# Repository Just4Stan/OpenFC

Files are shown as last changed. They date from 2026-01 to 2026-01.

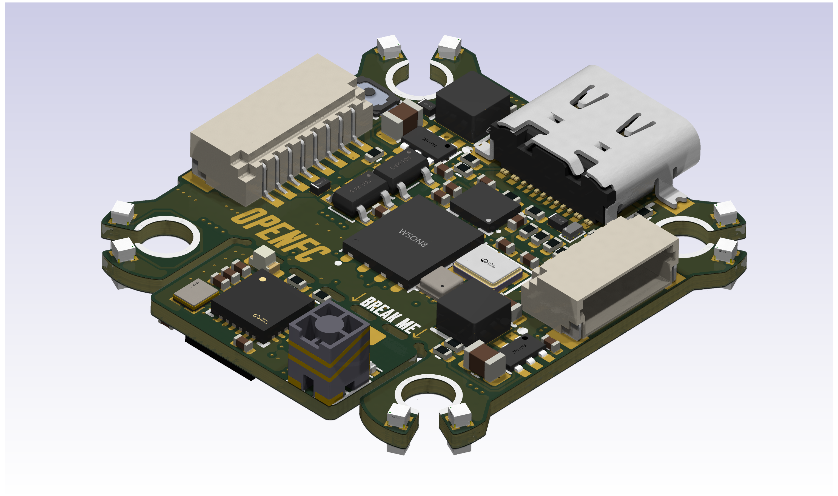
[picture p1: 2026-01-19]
images/OpenFC_Back.png

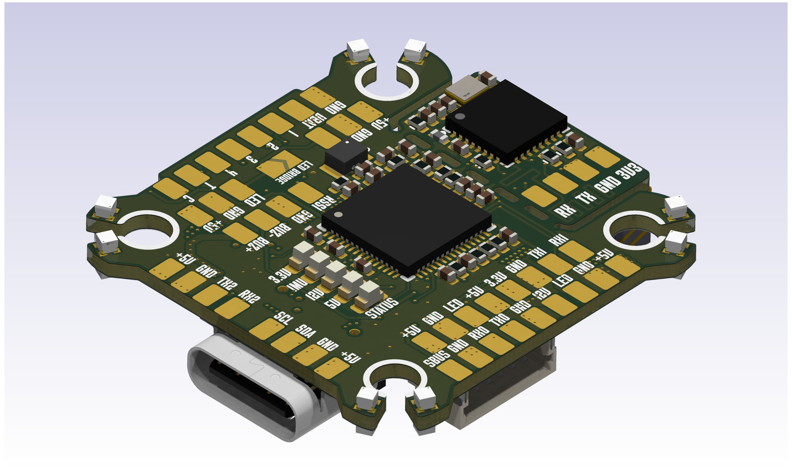
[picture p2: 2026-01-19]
images/OpenFC.png

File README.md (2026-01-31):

# OpenFC

Open-source Betaflight flight controller with integrated break-off ELRS receiver, based on the RP2354A microcontroller.


## Features

### Microcontroller
- **RP2354B** - Raspberry Pi dual-core ARM Cortex-M33 @ 150MHz (with integrated flash)

### Integrated ELRS Receiver (Break-off)
- On-board 2.4GHz ExpressLRS receiver module
- Break-off design allows for different placement if needed

### Sensors
- **IMU**: LSM6DSV16XTR 
- **Barometer**: BMI388

### Blackbox Data Logging
- **W25Q128JVPIQTR** - 128Mbit (16MB)

### Motor Outputs
- 4x PWM/DShot motor outputs

### Analog OSD on PIO
Hardware implementation of opamp and mux to detect syncs and select between white and black pixels. Needs software implementation still.

### Connectivity
- **USB-C** - Configuration and firmware flashing
- **UART0** - Serial RX/TX (ELRS connection pads)
- **UART1** - Spare serial port
- **PIO UART** - Software UART via RP2350 PIO (2x)
- **I2C** - External sensor expansion
- **SPI** - IMU and Blackbox on isolated bus.

### Analog Inputs
- Current sensor input (ADC)
- RSSI input (ADC)
- 1 external available ADC input

### Additional Features
- Addressable LED strip output (WS2812/NeoPixel)
- Buzzer output
- 16 LED's built in on corners
- ELRS ESP flashable by the RP2354B (BOOT/EN pins connected)

### Power
- 2S-6S batteries
- 10V and 5V regulated outputs, 10V is switchable.

## Repository Structure

```
OpenFC/
├── README.md
├── .gitignore
├── hardware/          ← KiCad project, libraries, and production files
│   ├── OpenFC.kicad_pro
│   ├── *.kicad_sch    ← Hierarchical schematics
│   ├── OpenFC.kicad_pcb
│   ├── lib.kicad_sym  ← Custom symbol library
│   ├── lib.pretty/    ← Custom footprint library
│   ├── lib.3dshapes/  ← 3D models
│   ├── production/    ← Gerbers, BOM, positions (all versions)
│   └── tools/         ← Analysis scripts
└── images/            ← Board renders
```

## Schematic Hierarchy

- `OpenFC.kicad_sch` - Top-level schematic
- `rp2350a.kicad_sch` - RP2354B microcontroller and supporting circuitry
- `elrs.kicad_sch` - ELRS 2.4GHz receiver module (break-off section)
- `Radioschematic.kicad_sch` - Radio/RF detailed schematic
- `power.kicad_sch` - Power supply and regulation
- `imu.kicad_sch` - LSM6DSV16XTR IMU
- `baro.kicad_sch` - BMP388 barometer
- `compass.kicad_sch` - LIS3MDLTR magnetometer (not populated, but there's space for it)
- `blackbox.kicad_sch` - W25Q128 flash memory
- `leds.kicad_sch` - Status LEDs
- `osd.kicad_sch` - OSD circuitry
- `connectors.kicad_sch` - External connectors
- `pads.kicad_sch` - Solder pads and test points

## Design Files

This project uses **KiCad 9.0** for schematic and PCB design. All symbol, footprint, and 3D model libraries are included in the repository — no external library setup is required.

## License

This project is open-source hardware. See LICENSE file for details.

## Contributing

Contributions are welcome! Please open an issue or submit a pull request.

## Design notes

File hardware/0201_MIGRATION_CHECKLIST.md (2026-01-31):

# 0201 Migration Checklist

## Summary
- Total passives: 33
- Can migrate to 0201: 31
- Cannot migrate: 2
- Already 0201: 0

## Can Migrate to 0201

| Ref | Value | Current Package | Notes |
|-----|---|---|---|
| C1 | 1u | 0402 |  |
| C3 | 10n | 0402 |  |
| C4 | 470n, 10V | 0402 |  |
| C5 | 10n | 0402 |  |
| C6 | 100n | 0402 |  |
| C7 | 100n | 0402 |  |
| C8 | 100n | 0402 |  |
| C10 | 1u 25v | 0402 |  |
| C11 | 10n | 0402 |  |
| C12 | 470n, 10V | 0402 |  |
| C13 | 10n | 0402 |  |
| C14 | 100n | 0402 |  |
| C15 | 100n | 0402 |  |
| C16 | 100n | 0402 |  |
| C17 | 10p | 0402 |  |
| C18 | 100n | 0402 |  |
| C19 | 1.2p | 0402 |  |
| C20 | 10p | 0402 |  |
| C21 | 100n | 0402 |  |
| C22 | 1.2p | 0402 |  |
| C23 | 1n | 0402 |  |
| C24 | 1u | 0402 |  |
| C25 | 1u | 0402 |  |
| C26 | 1.2p | 0402 |  |
| C27 | 1.2p | 0402 |  |
| R1 | 10k | 0402 |  |
| R2 | 10k | 0402 |  |
| R3 | 100k | 0402 |  |
| R4 | 100k | 0402 |  |
| R7 | 100k | 0402 |  |
| R8 | 100k | 0402 |  |

## Cannot Migrate

| Ref | Value | Current Package | Reason |
|-----|---|---|---|
| C2 | 2.2u | 0402 | Capacitance too high for 0201 |
| C9 | 10u | 0402 | Capacitance too high for 0201 |

## Already 0201

| Ref | Value |
|-----|---|

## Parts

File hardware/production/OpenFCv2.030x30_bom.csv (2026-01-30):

Designator | Footprint | Quantity | Value | LCSC Part #
1.8_IMU1, 12V1, 3V3CPU1, 5V1, 5V_PWR1, 5V_USB1, BL_FILT1, BPWM1, CLRSEL1, LEDLOW1, MUX_OUT1, PXLSEL1, SBUS1, SW12V1, SW5V1, SWC1, SWD1, SYNC1, SYNC_FILT1, SYNPWM1, VID_AC1, WH_FILT1, WPWM1 | TestPoint_Pad_D1.5mm | 23 | TestPoint
C1, C9 | 0402 | 2 | 10nF | C15195
C10, C11, C111, C12, C13, C14, C18, C19, C3, C32, C33, C34, C39, C41, C45, C46, C47, C49, C5, C50, C51, C52, C53, C55, C57, C58, C60, C61, C64, C70, C72, C75, C76, C78, C79, C8, C80, C81, C82, C83, C84, C85, C86, C87 | 0402 | 44 | 100n | C1525
C15 | 0402 | 1 | 1n
C16, C17, C2 | 0402 | 3 | 22uF | C105226
C35, C37 | 0805 | 2 | 4.7uF 50v | C98192
C36 | 0402 | 1 | 100nF | C1525
C38, C40, C48 | 0603 | 3 | 22uF | C2762594
C4, C6 | 0402 | 2 | 12p | C441742
C67, C68, C71, C77 | 0402 | 4 | 4.7uF | C23733
C7 | 0402 | 1 | 470nF | C92361
C73, C74 | 0402 | 2 | 20p | C441742
D1, D4, D5, D6, D7 | 0603 | 5 | LED_1_Green | C2994781
D2, D21, D3 | SOD-882_L1.0-W0.6-RD | 3 | RB161QS-40_C28646385 | C28646385
D8 | SOT-23-6_L2.9-W1.6-P0.95-LS2.8-BL | 1 | USBLC6-2SC6 | C7519
FL1, FL2 | FILTER-SMD_4P-L1.0-W0.5-L | 2 | DEA102700LT-6307A2 | C574024
J1, J10, J11, J12, J13, J14, J15, J16, J17, J18, J19, J2, J20, J21, J22, J23, J24, J25, J26, J27, J28, J29, J3, J30, J31, J32, J33, J34, J35, J36, J38, J39, J4, J40, J41, J42, J43, J44, J45, J46, J47, J48, J49, J5, J50, J51, J52, J53, J54, J55, J56, J57, J58, J59, J6, J7, J8, J9 | small_pad | 58 | 5V
L1 | IND-SMD_L2.0-W1.6_AOTA-B201610S3R3-101-T | 1 | AOTA-B201610S3R3-101-T | C42411119
L3, L4 | IND-SMD_L3.0-W3.0_AFE303020S | 2 | XRTC303020D4R7MBCA | C39846837
L7 | L0402 | 1 | LQG15HS2N0S02D | C18216
OSC1 | OSC-SMD_4P-L2.0-W1.6-BL_TXC_7Z | 1 | OW7EL89CENUNFAYLC-52M | C22434896
P1 | CONN-TH_SM08B-SRSS-TB-LF-SN | 1 | SM08B-SRSS-TB(LF)(SN) | C160407
Q1, Q2, Q7 | DFN-3L_L1.0-W0.6-P0.65-BR | 3 | DMN1150UFB-7B | C459538
R1, R3, R40, R47, R54, R6 | 0402 | 6 | 10k | C2909316
R10, R21, R30 | 0402 | 3 | 10k
R11, R13 | 0402 | 2 | 1k | C106235
R12, R15, R55 | 0402 | 3 | 200R | C25087
R14, R16, R17, R46, R5, R7 | 0402 | 6 | 100k | C60491
R18 | 0402 | 1 | 75R
R19 | 0402 | 1 | 10k | C25087
R2, R24 | 0402 | 2 | 1k
R20 | 0402 | 1 | 10k | C106235
R22, R4, R48, R49, R56 | 0402 | 5 | 30R | C138007
R23, R26, R34 | 0402 | 3 | 1k | C2909316
R25 | 0402 | 1 | 100k
R27, R32 | 0402 | 2 | 33R
R28 | 0402 | 1 | 5.23k | C2684530
R29 | 0402 | 1 | 470 | C114877
R31 | 0402 | 1 | 13.7k | C2933072
R33 | 0402 | 1 | 100R
R42 | 0402 | 1 | 6.8k | C105872
R43 | 0402 | 1 | 6.8k | C2906876
R51, R52 | 0402 | 2 | 5.1k | C105872
R8 | 0402 | 1 | 39k | C137995
RF1 | IPEX-SMD_3P-L2.6-W2.6-LS3.0 | 1 | CONUFL001-SMD-T | C22418213
U1 | CONN-SMD_SM06B-SRSS-TB-LF-SN | 1 | SM06B-SRSS-TB(LF)(SN) | C160405
U11 | UQFN-10_L1.8-W1.4-P0.40-TL | 1 | PI3A223ZMEX | C2673436
U12 | UDFN-4_L1.0-W1.0-P0.65-TL | 1 | WL9005D4-33 | C5357206
U13 | WSON-6-1EP_2x2mm_P0.65mm_EP1x1.6mm | 1 | TPS746-3.3DRV | C2868202
U14 | LGA-14_L3.0-W2.5-P0.50-BR | 1 | LSM6DSV16XTR | C5267406
U15, U16, U17, U18, U19, U22, U23, U24, U25, U26, U27, U28, U29, U3, U4, U5, U8 | LED-SMD_4P-L1.0-W1.0-TL_XL-1010RGBC-WS2812B | 17 | XL-1010RGBC-WS2812B | C5349953
U2 | QFN-32_L5.0-W5.0-P0.50-TL-EP3.7 | 1 | ESP32-C3FH4 | C2858491
U20 | QFN-24_L4.0-W4.0-P0.50-TL-EP2.6 | 1 | SX1281IMLTRT | C2151551
U21 | WDFN-6_L2.0-W2.0-P0.65-BL-EP | 1 | NCV8187AMT180TAG | C893189
U30 | SENSORM-SMD_BMP388 | 1 | BMP388 | C779278
U33 | SOT-583-8_L2.1-W1.6-P0.50-LS1.6-BL | 1 | TPS2116DRLR | C3235557
U36 | QFN-80_L10.0-W10.0-P0.40-TL-EP3.4 | 1 | RP2354B_C39843328 | C39843328
U37 | WSON-8-1EP_2x2mm_P0.5mm_EP0.9x1.6mm | 1 | GS8052-FR | C605423
U41 | SW-SMD_4P-L3.0-W2.0-P0.85-LS3.5 | 1 | TS2306A 240GF MSM 9_C2976675 | C2976675
U42 | SC-70-6_L2.0-W1.3-P0.65-LS2.1-BL | 1 | TXU0101DCKR | C5217868
U6, U7 | SOT-23-6_L2.9-W1.6-P0.95-LS2.9-BL | 2 | LMR51420YDDCR | C5383002
U9 | WSON-8_L6.0-W5.0-P1.27-BL-EP | 1 | BY25Q128ASWIG(R) | C394872
USB1 | USB-TYPE-C-SMD_TYPE-C-16P-QTWT | 1 | TYPE-C 16P QTWT | C5187472
X1 | CRYSTAL-SMD_4P-L2.5-W2.0-BL-A | 1 | XTM25012000JT00351001 | C37635340
X2 | CRYSTAL-SMD_4P-L1.6-W1.2-BL | 1 | SX0B40.000F0810F30 | C7301926

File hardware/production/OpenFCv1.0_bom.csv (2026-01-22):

Designator | Footprint | Quantity | Value | LCSC Part #
C1, C9 | 0402 | 2 | 10nF | C15195
C10, C11, C111, C12, C13, C14, C15, C18, C19, C2, C20, C24, C25, C26, C27, C28, C29, C30, C31, C32, C33, C34, C4, C41, C42, C44, C45, C46, C47, C49, C5, C50, C51, C52, C53, C54, C55, C56, C57, C58, C60, C69, C71, C75, C76, C8 | 0402 | 46 | 100n | C1525
C16, C17, C43 | 0402 | 3 | 22uF | C105226
C21, C22, C23, C6 | 0402 | 4 | 4.7uF | C23733
C3, C59 | 0402 | 2 | 15p | C441742
C35, C37 | 0805 | 2 | 4.7uF 50v | C98192
C36, C39 | 0402 | 2 | 100nF
C38, C40, C48 | 0603 | 3 | 22uF | C2762594
C7 | 0402 | 1 | 470nF | C92361
D1, D4, D5, D8 | 0603 | 4 | LED_1_Green | C2994781
D2 | SOT-23-6_L2.9-W1.6-P0.95-LS2.8-BL | 1 | USBLC6-2SC6 | C7519
D21, D3 | SOD-882_L1.0-W0.6-RD | 2 | RB161QS-40_C28646385 | C28646385
D6 | 0603 | 1 | LED_1_Green
FL1, FL2 | FILTER-SMD_4P-L1.0-W0.5-L | 2 | 2450FM07D0034T | C2651081
J1, J10, J11, J12, J13, J14, J15, J16, J17, J18, J19, J2, J20, J21, J22, J23, J24, J25, J26, J27, J28, J29, J3, J30, J31, J32, J33, J34, J35, J36, J38, J39, J4, J40, J42, J43, J44, J45, J46, J47, J48, J49, J5, J50, J53, J56, J6, J7, J8, J9 | small_pad | 50 | 5V
L1 | L0402 | 1 | BLM15AG601SN1D | C76884
L2 | IND-SMD_L2.0-W1.6_AOTA-B201610S3R3-101-T | 1 | AOTA-B201610S3R3-101-T | C42411119
L3, L4 | IND-SMD_L3.0-W3.0_AFE303020S | 2 | XRTC303020D4R7MBCA | C39846837
L7 | L0402 | 1 | LQG15HS2N0S02D | C18216
OSC1 | OSC-SMD_4P-L2.0-W1.6-BL_TXC_7Z | 1 | OW7EL89CENUNFAYLC-52M | C22434896
P1 | CONN-TH_SM08B-SRSS-TB-LF-SN | 1 | SM08B-SRSS-TB(LF)(SN) | C160407
Q7 | DFN-3L_L1.0-W0.6-P0.65-BR | 1 | DMN1150UFB-7B | C459538
R1, R11, R25, R26, R3, R6, R9 | 0402 | 7 | 10k | C2909316
R10, R34, R36, R37 | 0402 | 4 | 6.8k
R13 | 0402 | 1 | 1k | C106235
R14, R16, R5, R50, R7 | 0402 | 5 | 100k | C60491
R15, R20 | 0402 | 2 | 200R | C25087
R17, R18 | 0402 | 2 | 22R
R19, R21, R4 | 0402 | 3 | 33R | C25105
R2 | 0402 | 1 | 75 | C11702
R22 | 0402 | 1 | 30R
R23, R24, R44, R45 | 0402 | 4 | 5.1k | C105872
R28 | 0402 | 1 | 5.23k | C2684530
R29 | 0402 | 1 | 470 | C114877
R31 | 0402 | 1 | 13.7k | C2933072
R8 | 0402 | 1 | 39k | C137995
RF1 | IPEX-SMD_3P-L2.6-W2.6-LS3.0 | 1 | CONUFL001-SMD-T | C22418213
TP1, TP2, TP3 | TestPoint_Pad_D1.0mm | 3 | TestPoint
U1 | CONN-SMD_SM06B-SRSS-TB-LF-SN | 1 | SM06B-SRSS-TB(LF)(SN) | C160405
U10 | WSON-8_L6.0-W5.0-P1.27-TL-EP | 1 | GD25Q256EWIGR | C6564321
U12 | UDFN-4_L1.0-W1.0-P0.65-TL | 1 | WL9005D4-33 | C5357206
U13, U21 | WSON-6-1EP_2x2mm_P0.65mm_EP1x1.6mm | 2 | TPS746-3.3DRV
U14 | LGA-14_L3.0-W2.5-P0.50-BR | 1 | LSM6DSV16XTR | C5267406
U15, U16, U17, U18, U19, U22, U23, U24, U25, U26, U27, U28, U29, U3, U4, U5, U8 | LED-SMD_4P-L1.0-W1.0-TL_XL-1010RGBC-WS2812B | 17 | XL-1010RGBC-WS2812B | C5349953
U2 | QFN-32_L5.0-W5.0-P0.50-TL-EP3.7 | 1 | ESP32-C3FH4 | C2858491
U20 | QFN-24_L4.0-W4.0-P0.50-TL-EP2.6 | 1 | SX1281IMLTRT | C2151551
U30 | SENSORM-SMD_BMP388 | 1 | BMP388 | C779278
U32 | QFN-60_L7.0-W7.0-P0.40-TL-EP3.4 | 1 | RP2354A | C41378174
U33 | SOT-583-8_L2.1-W1.6-P0.50-LS1.6-BL | 1 | TPS2116DRLR | C3235557
U34 | SW-SMD_4P-L3.0-W2.0-P0.85-LS3.5 | 1 | TS2306A 240GF MSM 9_C2976675 | C2976675
U35 | QFN-32-1EP_5x5mm_P0.5mm_EP3.1x3.1mm | 1 | STM32G431KBUx | C1341901
U6, U7 | SOT-23-6_L2.9-W1.6-P0.95-LS2.9-BL | 2 | LMR51420YDDCR | C5383002
U9 | SC-70-6_L2.0-W1.3-P0.65-LS2.1-BL | 1 | TXU0101DCKR | C5217868
USB2 | USB-TYPE-C-SMD_TYPE-C-16P-QTWT | 1 | TYPE-C 16P QTWT | C5187472
X3 | OSC-SMD_4P-L1.6-W1.2-BL-1 | 1 | OT4EL89CJI-111YLC-12M | C42930209

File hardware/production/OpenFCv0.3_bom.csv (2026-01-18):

Designator | Footprint | Quantity | Value | LCSC Part #
AE1 | ANT-SMD_47948-0001 | 1 | 47948-0001 | C152351
C1, C9 | 0402 | 2 | 10nF | C15195
C11, C110, C111, C12, C13, C15, C2, C20, C24, C25, C26, C27, C28, C29, C30, C31, C34, C41, C42, C5, C8 | 0402 | 21 | 100n | C1525
C14, C17 | 0402 | 2 | 1.2p | C327292
C18, C19, C32, C33 | 0402 | 4 | 15p | C441742
C21, C22, C23, C6 | 0402 | 4 | 4.7uF | C23733
C3, C4 | 0402 | 2 | 22uF | C105226
C35, C37 | 0805 | 2 | 4.7uF 50v | C98192
C36, C39 | 0402 | 2 | 100nF
C38, C40 | 0603 | 2 | 22uF | C2762594
C7 | 0402 | 1 | 470nF | C92361
D1, D3, D4, D5 | 0603 | 4 | LED_1_Green | C2994781
D20, D21, D23 | SOD-882_L1.0-W0.6-RD | 3 | RB161QS-40_C28646385 | C28646385
D6 | 0603 | 1 | LED_1_Green
D7 | 0603 | 1 | LED | C2286
FL1 | FILTER-SMD_4P-L1.0-W0.5-L | 1 | 2450FM07D0034T | C2651081
J1, J13, J14, J15, J16, J17, J18, J19, J2, J20, J21, J22, J23, J24, J25, J26, J27, J28, J29, J3, J30, J31, J32, J33, J34, J35, J36, J37, J38, J39, J4, J40, J41, J42, J43, J44, J45, J46, J47, J48, J5, J53, J56, J59, J6, J7, J8, J9 | small_pad | 48 | 5V
L1 | 0402 | 1 | 3n | C269824
L2 | IND-SMD_L2.0-W1.6_AOTA-B201610S3R3-101-T | 1 | AOTA-B201610S3R3-101-T | C42411119
L3, L4 | IND-SMD_L3.0-W3.0_AFE303020S | 2 | XRTC303020D4R7MBCA | C39846837
L8 | L0402 | 1 | BLM15PD121SN1D | C76891
P1 | CONN-TH_SM08B-SRSS-TB-LF-SN | 1 | SM08B-SRSS-TB(LF)(SN) | C160407
Q7 | DFN-3L_L1.0-W0.6-P0.65-BR | 1 | DMN1150UFB-7B | C459538
R11, R25, R26, R6, R8, R9 | 0402 | 6 | 10k | C2909316
R13, R21 | 0402 | 2 | 1k | C106235
R14, R16, R5, R50 | 0402 | 4 | 100k | C60491
R15, R20 | 0402 | 2 | 200R | C25087
R17, R18 | 0402 | 2 | 22R
R19, R3, R4 | 0402 | 3 | 33R | C25105
R22 | 0402 | 1 | 30R
R23, R24, R44, R45 | 0402 | 4 | 5.1k | C105872
R28 | 0402 | 1 | 5.23k | C2684530
R29 | 0402 | 1 | 470 | C114877
R31 | 0402 | 1 | 13.7k | C2933072
R33 | 0402 | 1 | 3.3k | C25890
R35 | 0402 | 1 | 10k | C25744
R7 | 0402 | 1 | 12k | C2909316
U1 | CONN-SMD_SM06B-SRSS-TB-LF-SN | 1 | SM06B-SRSS-TB(LF)(SN) | C160405
U10, U9 | SOT-23-5_L3.0-W1.7-P0.95-LS2.8-BR | 2 | TLV75533PDBVR | C404027
U14 | LGA-14_L3.0-W2.5-P0.50-BR | 1 | LSM6DSV16XTR | C5267406
U15, U16, U17, U18, U22, U23, U24, U25, U26, U27, U28, U29, U3, U4, U5, U8 | LED-SMD_4P-L1.0-W1.0-TL_XL-1010RGBC-WS2812B | 16 | XL-1010RGBC-WS2812B | C5349953
U19 | QFN-32_L5.0-W5.0-P0.50-TL-EP3.7 | 1 | ESP8285H16 | C967019
U2 | WSON-8_L6.0-W5.0-P1.27-BL-EP | 1 | W25Q128JVPIQTR | C190862
U20 | QFN-24_L4.0-W4.0-P0.50-TL-EP2.6 | 1 | SX1281IMLTRT | C2151551
U30 | SENSORM-SMD_BMP388 | 1 | BMP388 | C779278
U32 | QFN-60_L7.0-W7.0-P0.40-TL-EP3.4 | 1 | RP2354A | C41378174
U33 | CRYSTAL-SMD_4P-L3.2-W2.5-BL | 1 | ABM8-272-T3_C20625731 | C20625731
U34 | SW-SMD_4P-L3.0-W2.0-P0.85-LS3.5 | 1 | TS2306A 240GF MSM 9_C2976675 | C2976675
U6, U7 | SOT-23-6_L2.9-W1.6-P0.95-LS2.9-BL | 2 | LMR51420YDDCR | C5383002
USB2 | USB-TYPE-C-SMD_TYPE-C-16P-QTWT | 1 | TYPE-C 16P QTWT | C5187472
X1 | CRYSTAL-SMD_4P-L2.0-W1.6-BL | 1 | XTM20026000FT00351005 | C37635330
X2 | CRYSTAL-SMD_4P-L2.0-W1.6-BL | 1 | Q22FA12800519 | C841202

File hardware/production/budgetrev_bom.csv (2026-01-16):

Designator | Footprint | Quantity | Value | LCSC Part #
AE2 | ANT-SMD_47948-0001 | 1 | 47948-0001 | C152351
C1, C2, C83, C84, C85, C86 | 0402 | 6 | 1.2p | C327292
C100, C101, C102, C103, C104, C107, C109, C110, C111, C113, C41, C46, C47, C48, C79, C80, C81, C82, C97, C98, C99 | 0402 | 21 | 100n | C1525
C105, C106 | 0402 | 2 | 15p | C441742
C108, C36, C39, C76, C77, C87, C90, C93, C95 | 0402 | 9 | 100nF
C3, C4 | 0402 | 2 | 22uF | C105226
C35, C37 | 0805 | 2 | 4.7uF 50v | C98192
C38, C40 | 0603 | 2 | 22uF | C2762594
C42, C43, C44, C45 | 0402 | 4 | 4.7uF | C23733
C78 | 0402 | 1 | 1uF
C88, C91, C94, C96 | 0402 | 4 | 10nF
C89, C92 | 0402 | 2 | 470nF
D1, D18, D2, D3, D4 | 0603 | 5 | LED_1_Green
D20, D21, D23 | SOD-882_L1.0-W0.6-RD | 3 | RB161QS-40_C28646385 | C28646385
FL3, FL4 | FILTER-SMD_5P-L2.0-W1.3-L | 2 | DEA202450BT-3030A1 | C307660
J1_2, J1, J10, J11, J12, J13, J14, J15, J16, J17, J18, J19, J2_2, J2, J20, J21, J22, J23, J24_2, J24, J25_2, J25, J26_2, J26, J27_2, J27, J28, J29, J3_2, J3, J30, J35, J36, J37, J38, J39, J4_2, J4, J40, J41, J42, J43, J44, J45, J46, J47, J48, J49, J5, J50, J51, J52, J53, J54, J55, J56, J57, J58, J6, J7, J8, J9 | small_pad | 62 | 5V
JP4 | RF-SMD_FRF05002-JSS103M | 1 | U.FL-R-SMT-1(80) | C88374
L1, L12 | L0805 | 2 | MGFL2012F150MT-LF (15uH) | C486333
L10, L11, L6 | L0402 | 3 | LQW15AN3N0B00D (3nH) | C269824
L2 | ANT-SMD_L8.0-W1.0-SLDA81-3R010G-S1TF | 1 | ANT8010LL04R2400A | C723634
L3, L4 | IND-SMD_L3.0-W3.0_AFE303020S | 2 | XRTC303020D4R7MBCA | C39846837
L5 | IND-SMD_PSTMAA160808-4R7MB | 1 | FTC160808S3R3MBCA | C46594346
LED2 | LED-SMD_4P-L2.0-W2.0-TL_WS2812B-2020 | 1 | WS2812B-2020 | C965555
OSC2 | OSC-SMD_4P-L2.0-W1.6-BL_TXC_7Z | 1 | OW7EL89CENUNFAYLC-52M | C22434896
P1 | CONN-TH_SM08B-SRSS-TB-LF-SN | 1 | SM08B-SRSS-TB(LF)(SN) | C160407
Q7 | DFN-3L_L1.0-W0.6-P0.65-BR | 1 | DMN1150UFB-7B | C459538
R1, R2, R44, R45 | 0402 | 4 | 5.1k
R19, R24, R40, R51 | 0402 | 4 | 10k
R20, R21, R22, R23 | 0402 | 4 | 100k | C25744
R27, R30, R5, R50 | 0402 | 4 | 100k
R28 | 0402 | 1 | 5.23k
R29 | 0402 | 1 | 470
R3, R4, R53 | 0402 | 3 | 30R
R31 | 0402 | 1 | 13.7k
R32 | 0402 | 1 | 200
R39 | 0402 | 1 | 33R
R41 | 0402 | 1 | 200R
R42, R43, R49 | 0402 | 3 | 1k
R46, R47 | 0402 | 2 | 22R
SW1 | KEY-SMD_B3U-1000PM | 1 | B3U-1000P | C231329
U1 | CONN-SMD_SM06B-SRSS-TB-LF-SN | 1 | SM06B-SRSS-TB(LF)(SN) | C160405
U10, U9 | SOT-23-5_L3.0-W1.7-P0.95-LS2.8-BR | 2 | TLV75533PDBVR | C404027
U11 | QFN-60_L7.0-W7.0-P0.40-TL-EP3.4 | 1 | RP2350A_C42411118 | C42411118
U12 | CRYSTAL-SMD_4P-L3.2-W2.5-BL | 1 | ABM8-272-T3_C20625731 | C20625731
U13 | USON-8_L3.0-W2.0-P0.50-BL-EP | 1 | W25Q32RVXHJQ TR | C32246052
U14 | LGA-14_L3.0-W2.5-P0.50-BR | 1 | LSM6DSV16XTR | C5267406
U15, U16, U17, U18, U3, U4, U5, U8 | LED-SMD_4P-L1.0-W1.0-TL_XL-1010RGBC-WS2812B | 8 | XL-1010RGBC-WS2812B | C5349953
U2 | WSON-8_L6.0-W5.0-P1.27-BL-EP | 1 | W25Q128JVPIQTR | C190862
U24, U25 | QFN-16_L3.0-W3.0-P0.50-BL-EP1.7 | 2 | RFX2401C | C19213
U26 | LGA-48_L7.0-W7.0-P0.50-BL-EP5.0 | 1 | ESP32-PICO-V3 | C967022
U27, U28 | QFN-24_L4.0-W4.0-P0.50-TL-EP2.6 | 2 | SX1281IMLTRT | C2151551
U30 | SENSORM-SMD_BMP388 | 1 | BMP388 | C779278
U31 | LGA-12_L2.0-W2.0-P0.50-BL | 1 | LIS3MDLTR | C478483
U6, U7 | SOT-23-6_L2.9-W1.6-P0.95-LS2.9-BL | 2 | LMR51420YDDCR | C5383002
USB1 | USB-C-SMD_TYPE-C-6PIN-2MD-073 | 1 | TYPE-C 16PIN 2MD(073) | C2765186

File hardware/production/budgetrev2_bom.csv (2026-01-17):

Designator | Footprint | Quantity | Value | LCSC Part #
AE1 | ANT-SMD_47948-0001 | 1 | 47948-0001 | C152351
C1, C9 | 0402 | 2 | 10nF | C15195
C10, C100, C101, C102, C103, C104, C109, C11, C110, C111, C12, C13, C2, C41, C46, C47, C48, C5, C8, C97, C98, C99 | 0402 | 22 | 100n | C1525
C105, C106, C18, C19 | 0402 | 4 | 15p | C441742
C14, C15, C17, C20 | 0402 | 4 | 1.2p | C327292
C3, C4 | 0402 | 2 | 22uF | C105226
C35, C37 | 0805 | 2 | 4.7uF 50v | C98192
C36, C39 | 0402 | 2 | 100nF
C38, C40 | 0603 | 2 | 22uF | C2762594
C42, C43, C44, C45 | 0402 | 4 | 4.7uF | C23733
C7 | 0402 | 1 | 470nF | C92361
D1, D3, D4, D5 | 0603 | 4 | LED_1_Green | C2994781
D2 | 0603 | 1 | LED_1_Green
D20, D21, D23 | SOD-882_L1.0-W0.6-RD | 3 | RB161QS-40_C28646385 | C28646385
J1, J13, J14, J15, J16, J17, J18, J19, J2, J20, J21, J22, J23, J24, J25, J26, J27, J28, J29, J3, J30, J31, J32, J33, J34, J35, J36, J37, J38, J39, J4, J40, J41, J42, J43, J44, J45, J46, J47, J48, J5, J53, J56, J57, J59, J6, J7, J8 | small_pad | 48 | 5V
L13 | ANT-SMD_L8.0-W1.0-SLDA81-3R010G-S1TF | 1 | ANT8010LL04R2400A | C723634
L3, L4 | IND-SMD_L3.0-W3.0_AFE303020S | 2 | XRTC303020D4R7MBCA | C39846837
L5 | IND-SMD_PSTMAA160808-4R7MB | 1 | FTC160808S3R3MBCA | C46594346
L7, L9 | L0402 | 2 | LQW15AN3N0B00D (3nH) | C269824
L8 | L0402 | 1 | BLM15PD121SN1D | C76891
OSC1 | OSC-SMD_4P-L2.0-W1.6-BL_TXC_7Z | 1 | OW7EL89CENUNFAYLC-52M | C22434896
P1 | CONN-TH_SM08B-SRSS-TB-LF-SN | 1 | SM08B-SRSS-TB(LF)(SN) | C160407
Q7 | DFN-3L_L1.0-W0.6-P0.65-BR | 1 | DMN1150UFB-7B | C459538
R1, R2, R44, R45 | 0402 | 4 | 5.1k | C105872
R10, R11, R12, R6, R8, R9 | 0402 | 6 | 10k | C2909316
R13, R42 | 0402 | 2 | 1k | C106235
R14, R16, R5, R50 | 0402 | 4 | 100k | C60491
R15, R41 | 0402 | 2 | 200R | C25087
R28 | 0402 | 1 | 5.23k | C2684530
R29 | 0402 | 1 | 470 | C114877
R3, R39, R4 | 0402 | 3 | 33R | C25105
R31 | 0402 | 1 | 13.7k | C114877
R46, R47 | 0402 | 2 | 22R
R53 | 0402 | 1 | 30R
R7 | 0402 | 1 | 12k | C2909316
U1 | CONN-SMD_SM06B-SRSS-TB-LF-SN | 1 | SM06B-SRSS-TB(LF)(SN) | C160405
U10, U9 | SOT-23-5_L3.0-W1.7-P0.95-LS2.8-BR | 2 | TLV75533PDBVR | C404027
U11 | QFN-60_L7.0-W7.0-P0.40-TL-EP3.4 | 1 | RP2350A_C42411118 | C42411118
U12 | CRYSTAL-SMD_4P-L3.2-W2.5-BL | 1 | ABM8-272-T3_C20625731 | C20625731
U13 | USON-8_L3.0-W2.0-P0.50-BL-EP | 1 | W25Q32RVXHJQ TR | C32246052
U14 | LGA-14_L3.0-W2.5-P0.50-BR | 1 | LSM6DSV16XTR | C5267406
U15, U16, U17, U18, U3, U4, U5, U8 | LED-SMD_4P-L1.0-W1.0-TL_XL-1010RGBC-WS2812B | 8 | XL-1010RGBC-WS2812B | C5349953
U19 | QFN-32_L5.0-W5.0-P0.50-TL-EP3.7 | 1 | ESP8285H16 | C967019
U2 | WSON-8_L6.0-W5.0-P1.27-BL-EP | 1 | W25Q128JVPIQTR | C190862
U20 | QFN-24_L4.0-W4.0-P0.50-TL-EP2.6 | 1 | SX1281IMLTRT | C2151551
U21 | SW-SMD_4P-L3.0-W2.0-P0.85-LS3.5 | 1 | TS2306A 240GF MSM 9_C2976675 | C2976675
U30 | SENSORM-SMD_BMP388 | 1 | BMP388 | C779278
U6, U7 | SOT-23-6_L2.9-W1.6-P0.95-LS2.9-BL | 2 | LMR51420YDDCR | C5383002
USB2 | USB-TYPE-C-SMD_TYPE-C-16P-QTWT | 1 | TYPE-C 16P QTWT | C5187472
X1 | CRYSTAL-SMD_4P-L2.0-W1.6-BL | 1 | XTM20026000FT00351005 | C37635330

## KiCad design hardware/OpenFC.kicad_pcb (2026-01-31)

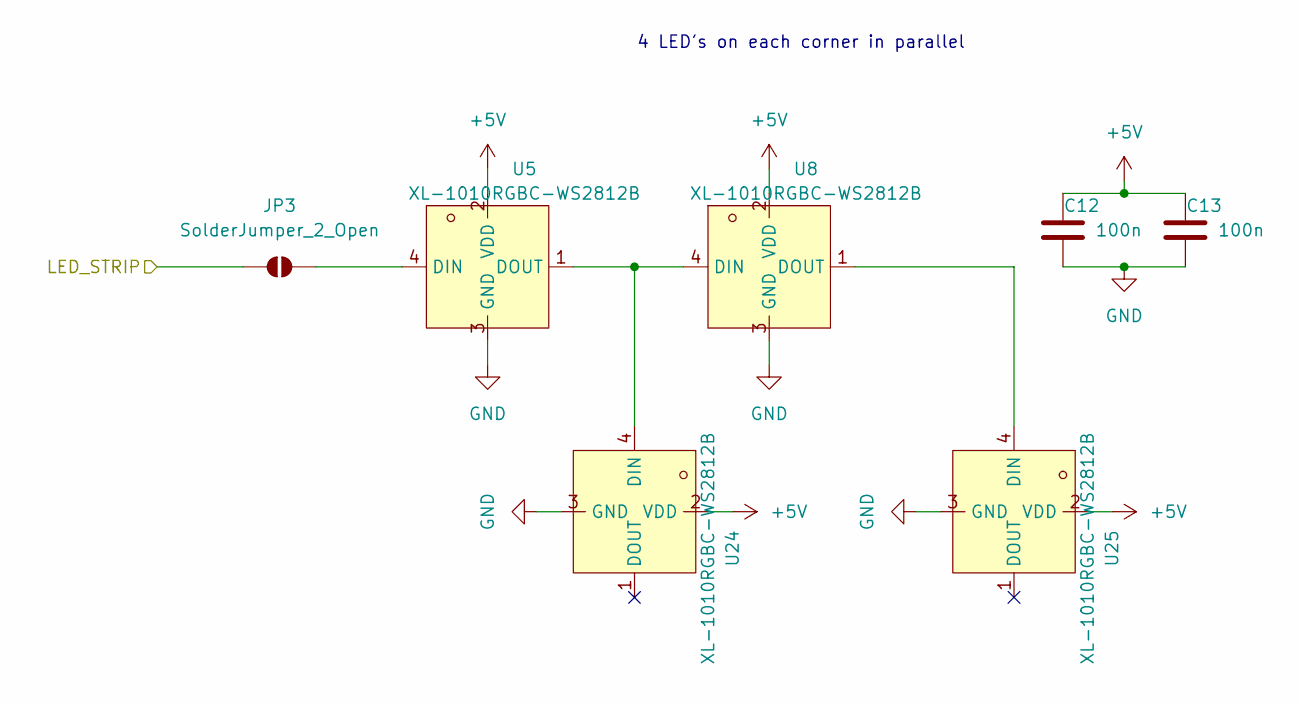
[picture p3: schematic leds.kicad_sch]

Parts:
C12, C13: 100n; C_0201_0603Metric; LCSC C76939
JP3: SolderJumper_2_Open; MouseBite-Slot-Jumper_0201
U5, U8, U24, U25: XL-1010RGBC-WS2812B; LED-SMD_4P-L1.0-W1.0-TL_XL-1010RGBC-WS2812B; LCSC Part C5349953

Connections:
+5V: C12.1, C13.1, U5.2 (VDD), U8.2 (VDD), U24.2 (VDD), U25.2 (VDD); also elsewhere on the board
/LED: JP3.1 (A); also elsewhere on the board
GND: C12.2, C13.2, U5.3 (GND), U8.3 (GND), U24.3 (GND), U25.3 (GND); also elsewhere on the board
unnamed: JP3.2 (B), U5.4 (DIN)
unnamed: U5.1 (DOUT), U8.4 (DIN), U24.4 (DIN)
unnamed: U8.1 (DOUT), U25.4 (DIN)

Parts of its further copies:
C18, C19, C46, C47, C57, C58: 100n; C_0201_0603Metric; LCSC C76939
JP1, JP2, JP4: SolderJumper_2_Open; MouseBite-Slot-Jumper_0201
U3, U4, U15, U16, U17, U18, U22, U23, U26, U27, U28, U29: XL-1010RGBC-WS2812B; LED-SMD_4P-L1.0-W1.0-TL_XL-1010RGBC-WS2812B; LCSC Part C5349953

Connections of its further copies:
+5V: C18.1, C19.1, C46.1, C47.1, C57.1, C58.1, U3.2 (VDD), U4.2 (VDD), U15.2 (VDD), U16.2 (VDD), U17.2 (VDD), U18.2 (VDD), U22.2 (VDD), U23.2 (VDD), U26.2 (VDD), U27.2 (VDD), U28.2 (VDD), U29.2 (VDD); also elsewhere on the board
/LED: JP1.1 (A), JP2.1 (A), JP4.1 (A); also elsewhere on the board
GND: C18.2, C19.2, C46.2, C47.2, C57.2, C58.2, U3.3 (GND), U4.3 (GND), U15.3 (GND), U16.3 (GND), U17.3 (GND), U18.3 (GND), U22.3 (GND), U23.3 (GND), U26.3 (GND), U27.3 (GND), U28.3 (GND), U29.3 (GND); also elsewhere on the board
unnamed: JP1.2 (B), U3.4 (DIN)
unnamed: JP2.2 (B), U17.4 (DIN)
unnamed: JP4.2 (B), U26.4 (DIN)
unnamed: U3.1 (DOUT), U4.4 (DIN), U15.4 (DIN)
unnamed: U15.1 (DOUT), U16.4 (DIN)
unnamed: U17.1 (DOUT), U18.4 (DIN), U22.4 (DIN)
unnamed: U22.1 (DOUT), U23.4 (DIN)
unnamed: U26.1 (DOUT), U27.4 (DIN), U28.4 (DIN)
unnamed: U28.1 (DOUT), U29.4 (DIN)

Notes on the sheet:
4 LED's on each corner in parallel

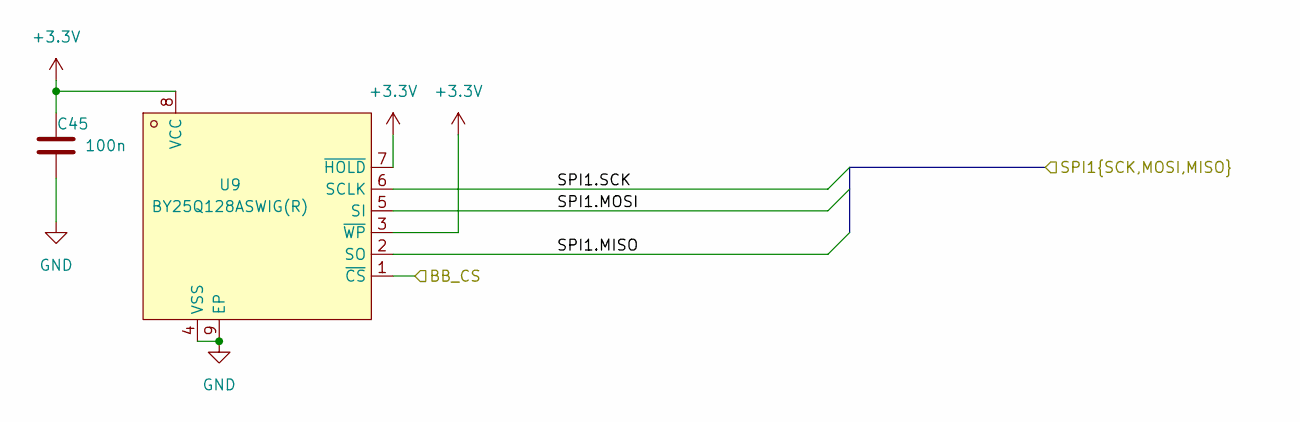
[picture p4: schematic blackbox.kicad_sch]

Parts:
C45: 100n; C_0201_0603Metric; LCSC C76939
U9: BY25Q128ASWIG(R); WSON-8_L6.0-W5.0-P1.27-BL-EP; LCSC Part C394872

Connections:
+3.3V: C45.1, U9.3 (~WP), U9.7 (~HOLD), U9.8 (VCC); also elsewhere on the board
/BLACKBOX/BB_CS: U9.1 (~CS); also elsewhere on the board
/BLACKBOX/SPI1.MISO: U9.2 (SO); also elsewhere on the board
/BLACKBOX/SPI1.MOSI: U9.5 (SI); also elsewhere on the board
/BLACKBOX/SPI1.SCK: U9.6 (SCLK); also elsewhere on the board
GND: C45.2, U9.4 (VSS), U9.9 (EP); also elsewhere on the board

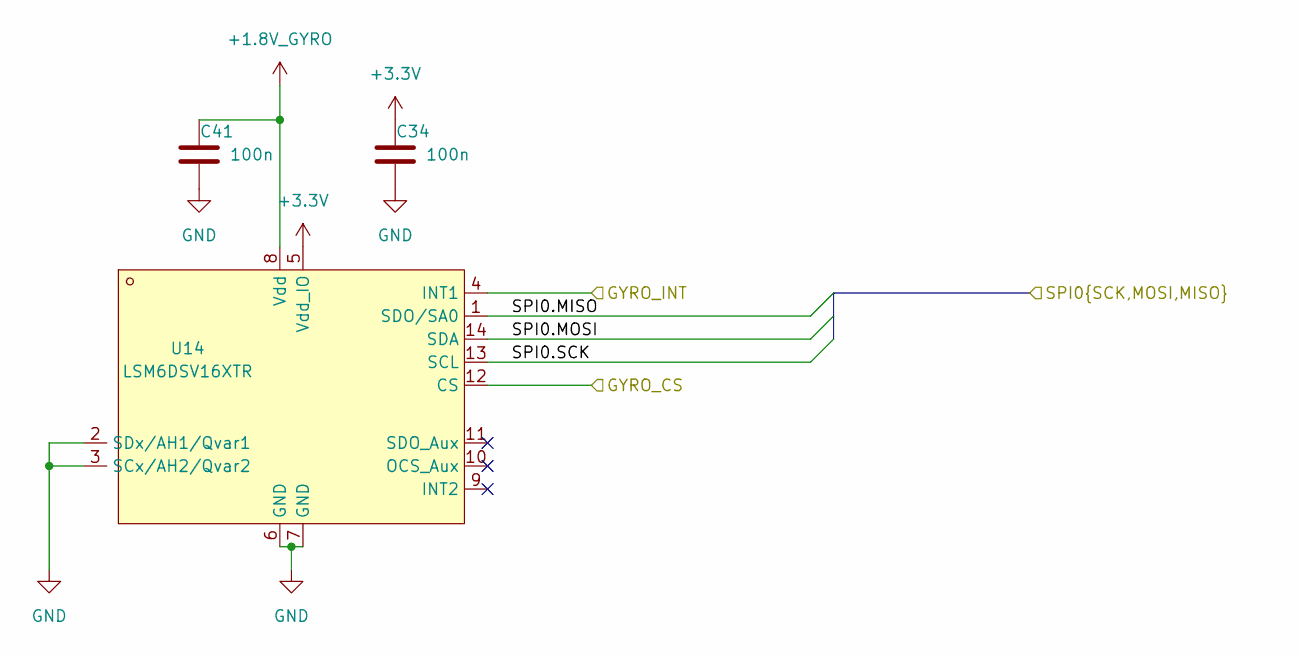
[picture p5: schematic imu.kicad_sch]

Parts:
C34, C41: 100n; C_0201_0603Metric; LCSC C76939
U14: LSM6DSV16XTR; LGA-14_L3.0-W2.5-P0.50-BR; LCSC Part C5267406

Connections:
+1.8V_GYRO: C41.1, U14.8 (Vdd); also elsewhere on the board
+3.3V: C34.1, U14.5 (Vdd_IO); also elsewhere on the board
/IMU/GYRO_CS: U14.12 (CS); also elsewhere on the board
/IMU/GYRO_INT: U14.4 (INT1); also elsewhere on the board
/IMU/SPI0.MISO: U14.1 (SDO/SA0); also elsewhere on the board
/IMU/SPI0.MOSI: U14.14 (SDA); also elsewhere on the board
/IMU/SPI0.SCK: U14.13 (SCL); also elsewhere on the board
GND: C34.2, C41.2, U14.2 (SDx/AH1/Qvar1), U14.3 (SCx/AH2/Qvar2), U14.6 (GND), U14.7 (GND); also elsewhere on the board

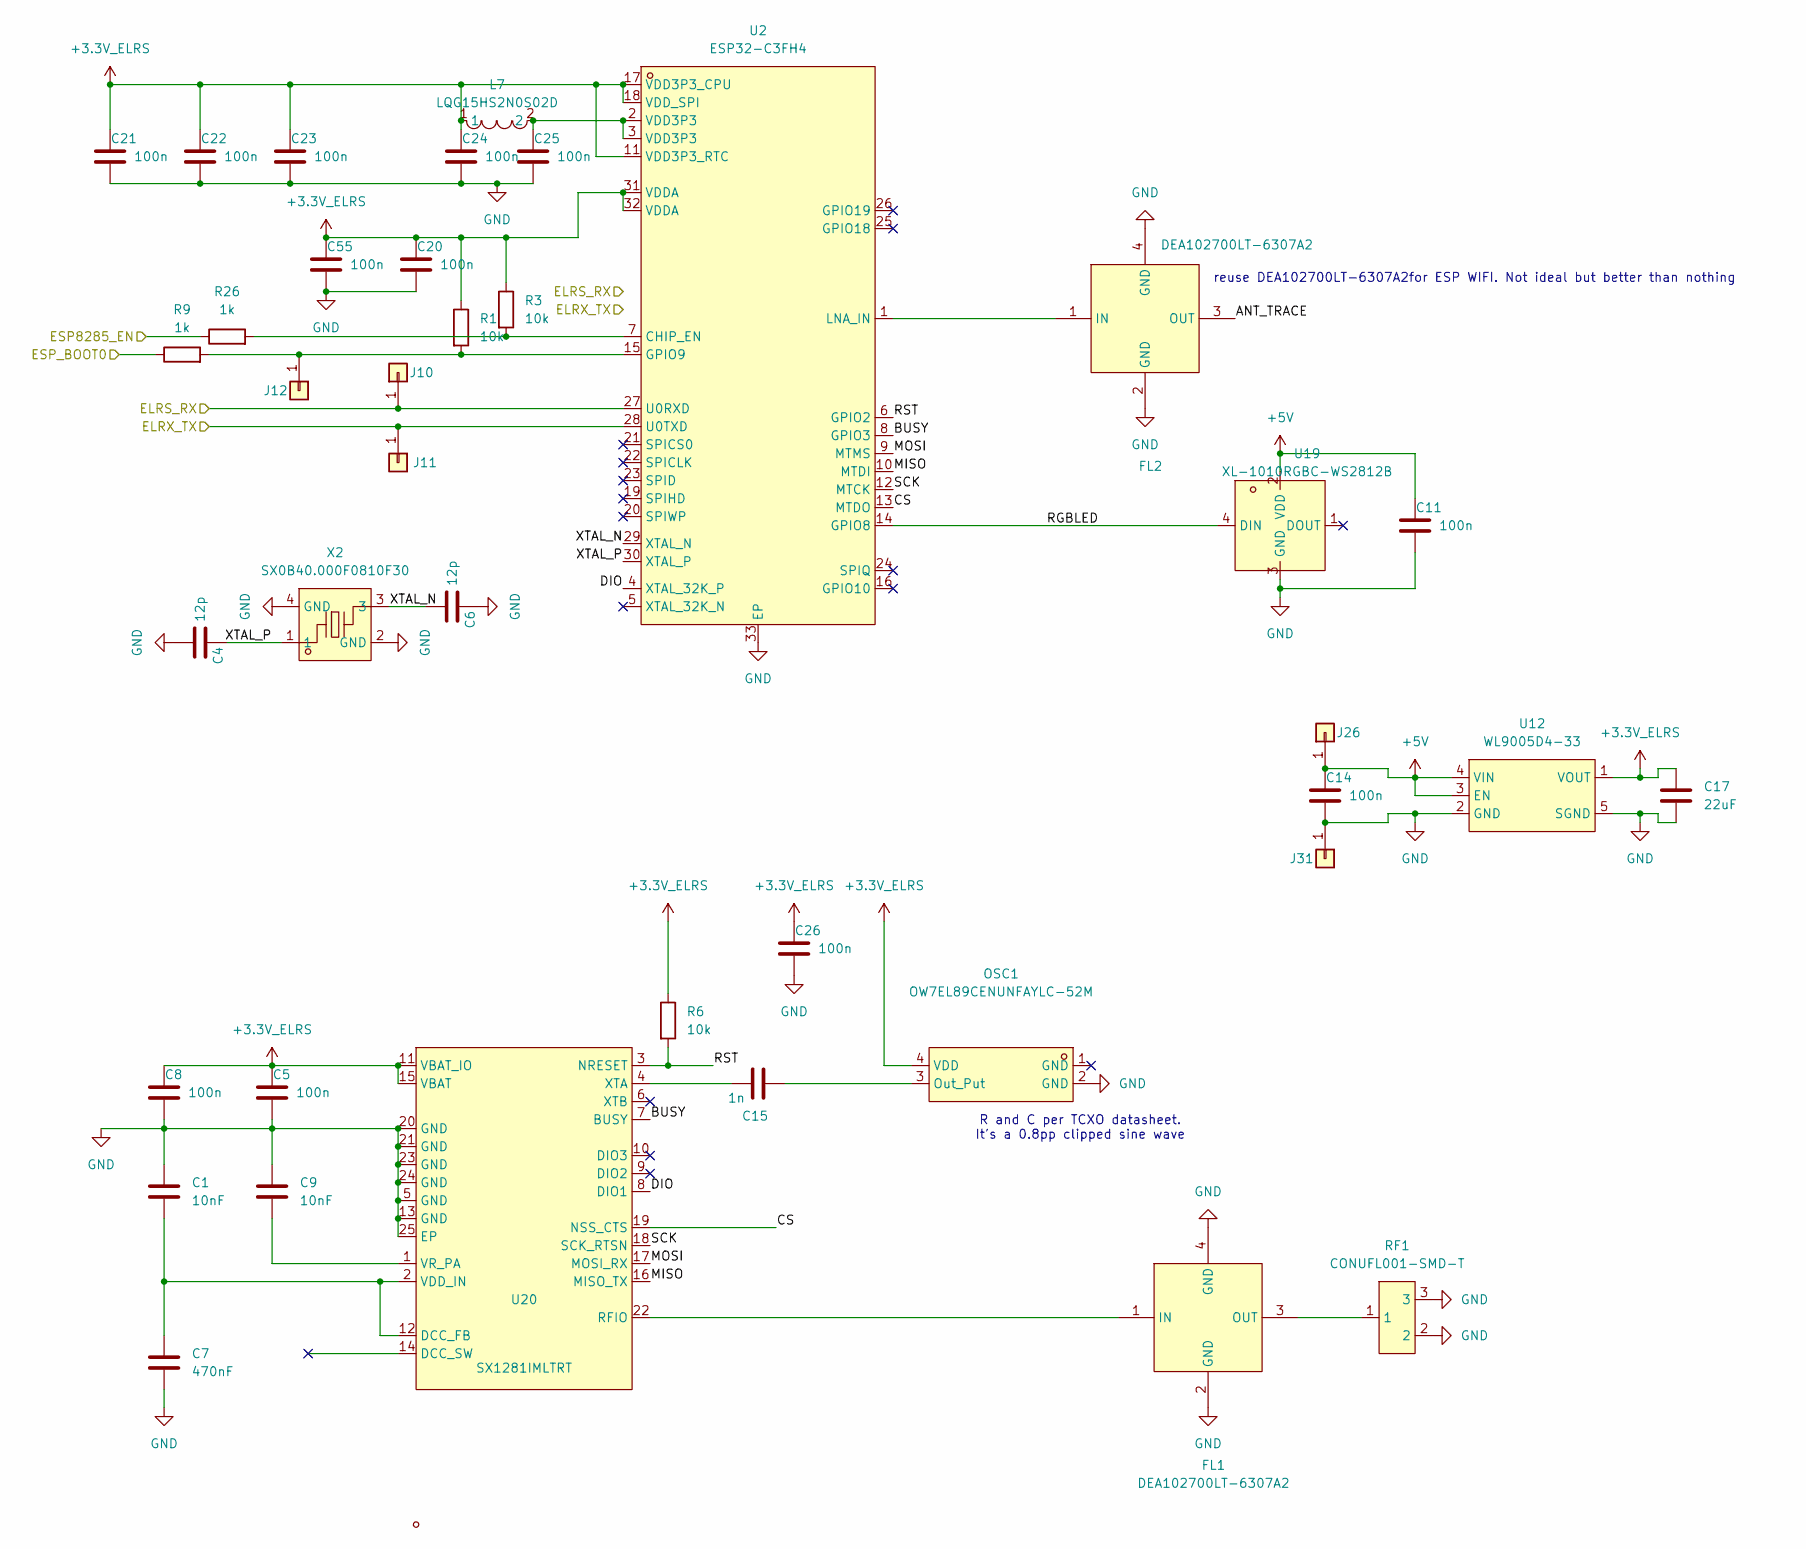
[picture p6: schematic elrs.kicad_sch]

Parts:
C1, C9: 10nF; C_0201_0603Metric; LCSC C76941
C4, C6: 12p; C_0201_0603Metric; LCSC C161404
C5, C8, C11, C14, C20, C21, C22, C23, C24, C25, C26, C55: 100n; C_0201_0603Metric; LCSC C76939
C7: 470nF; C_0201_0603Metric; LCSC C85926
C15: 1n; C_0201_0603Metric; LCSC C85934
C17: 22uF; C_0402_1005Metric; LCSC C105226
FL1, FL2: DEA102700LT-6307A2; FILTER-SMD_4P-L1.0-W0.5-L; LCSC Part C574024
J10, J11, J12, J26, J31: 5V; small_pad
L7: LQG15HS2N0S02D; L0402; LCSC Part C18216
OSC1: OW7EL89CENUNFAYLC-52M; OSC-SMD_4P-L2.0-W1.6-BL_TXC_7Z; LCSC Part C22434896
R1, R3, R6: 10k; C_0201_0603Metric; LCSC C473048
R9, R26: 1k; C_0201_0603Metric; LCSC C270365
RF1: CONUFL001-SMD-T; IPEX-SMD_3P-L2.6-W2.6-LS3.0; LCSC Part C22418213
U2: ESP32-C3FH4; QFN-32_L5.0-W5.0-P0.50-TL-EP3.7; LCSC Part C2858491
U12: WL9005D4-33; UDFN-4_L1.0-W1.0-P0.65-TL; LCSC Part C5357206
U19: XL-1010RGBC-WS2812B; LED-SMD_4P-L1.0-W1.0-TL_XL-1010RGBC-WS2812B; LCSC Part C5349953
U20: SX1281IMLTRT; QFN-24_L4.0-W4.0-P0.50-TL-EP2.6; LCSC Part C2151551
X2: SX0B40.000F0810F30; CRYSTAL-SMD_4P-L1.6-W1.2-BL; LCSC Part C7301926

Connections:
+3.3V_ELRS: C5.1, C8.1, C17.1, C20.1, C21.1, C22.1, C23.1, C24.1, C26.1, C55.1, L7.1, OSC1.4 (VDD), R1.1, R3.1, R6.1, U2.11 (VDD3P3_RTC), U2.17 (VDD3P3_CPU), U2.18 (VDD_SPI), U2.31 (VDDA), U2.32 (VDDA), U12.1 (VOUT), U20.11 (VBAT_IO), U20.15 (VBAT)
+5V: C11.1, C14.1, J26.1, U12.3 (EN), U12.4 (VIN), U19.2 (VDD); also elsewhere on the board
/ELRS/ANT_TRACE: FL2.3 (OUT)
/ELRS/BUSY: U2.8 (GPIO3), U20.7 (BUSY)
/ELRS/CS: U2.13 (MTDO), U20.19 (NSS_CTS)
/ELRS/DIO: U2.4 (XTAL_32K_P), U20.8 (DIO1)
/ELRS/ESP8285_EN: R26.1; also elsewhere on the board
/ELRS/ESP_BOOT0: R9.1; also elsewhere on the board
/ELRS/MISO: U2.10 (MTDI), U20.16 (MISO_TX)
/ELRS/MOSI: U2.9 (MTMS), U20.17 (MOSI_RX)
/ELRS/RGBLED: U2.14 (GPIO8), U19.4 (DIN)
/ELRS/RST: R6.2, U2.6 (GPIO2), U20.3 (NRESET)
/ELRS/SCK: U2.12 (MTCK), U20.18 (SCK_RTSN)
/ELRS/XTAL_N: C6.2, U2.29 (XTAL_N), X2.3
/ELRS/XTAL_P: C4.1, U2.30 (XTAL_P), X2.1
/UART1_RX: J11.1, U2.28 (U0TXD); also elsewhere on the board
/UART1_TX: J10.1, U2.27 (U0RXD); also elsewhere on the board
GND: C1.1, C4.2, C5.2, C6.1, C7.2, C8.2, C9.1, C11.2, C14.2, C17.2, C20.2, C21.2, C22.2, C23.2, C24.2, C25.2, C26.2, C55.2, FL1.2 (GND), FL1.4 (GND), FL2.2 (GND), FL2.4 (GND), J31.1, OSC1.2 (GND), RF1.2, RF1.3, U2.33 (EP), U12.2 (GND), U12.5 (SGND), U19.3 (GND), U20.5 (GND), U20.13 (GND), U20.20 (GND), U20.21 (GND), U20.23 (GND), U20.24 (GND), U20.25 (EP), X2.2 (GND), X2.4 (GND); also elsewhere on the board
unnamed: C25.1, L7.2, U2.2 (VDD3P3), U2.3 (VDD3P3)
unnamed: FL1.1 (IN), U20.22 (RFIO)
unnamed: FL1.3 (OUT), RF1.1
unnamed: FL2.1 (IN), U2.1 (LNA_IN)
unnamed: J12.1, R1.2, R9.2, U2.15 (GPIO9)
unnamed: C15.2, OSC1.3 (Out_Put)
unnamed: R3.2, R26.2, U2.7 (CHIP_EN)
unnamed: C1.2, C7.1, U20.2 (VDD_IN), U20.12 (DCC_FB)
unnamed: C9.2, U20.1 (VR_PA)
unnamed: C15.1, U20.4 (XTA)

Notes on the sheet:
reuse DEA102700LT-6307A2for ESP WIFI. Not ideal but better than nothing
R and C per TCXO datasheet. It's a 0.8pp clipped sine wave

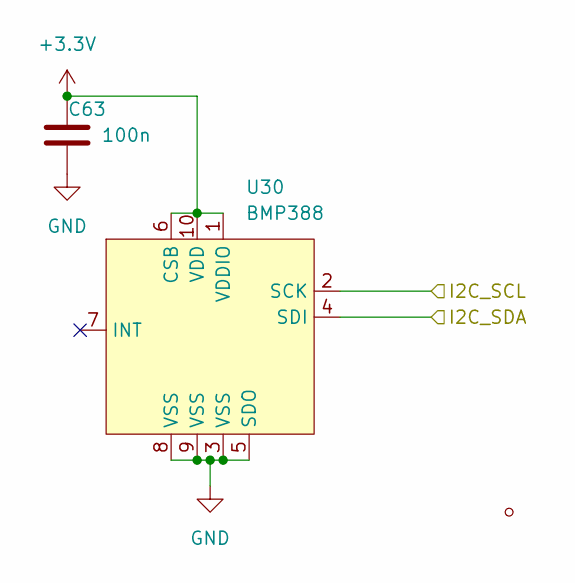
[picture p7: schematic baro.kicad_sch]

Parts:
C63: 100n; C_0201_0603Metric; LCSC C76939
U30: BMP388; SENSORM-SMD_BMP388; LCSC Part C779278

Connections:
+3.3V: C63.1, U30.1 (VDDIO), U30.6 (CSB), U30.10 (VDD); also elsewhere on the board
/I2C_SCL: U30.2 (SCK); also elsewhere on the board
/I2C_SDA: U30.4 (SDI); also elsewhere on the board
GND: C63.2, U30.3 (VSS), U30.5 (SDO), U30.8 (VSS), U30.9 (VSS); also elsewhere on the board

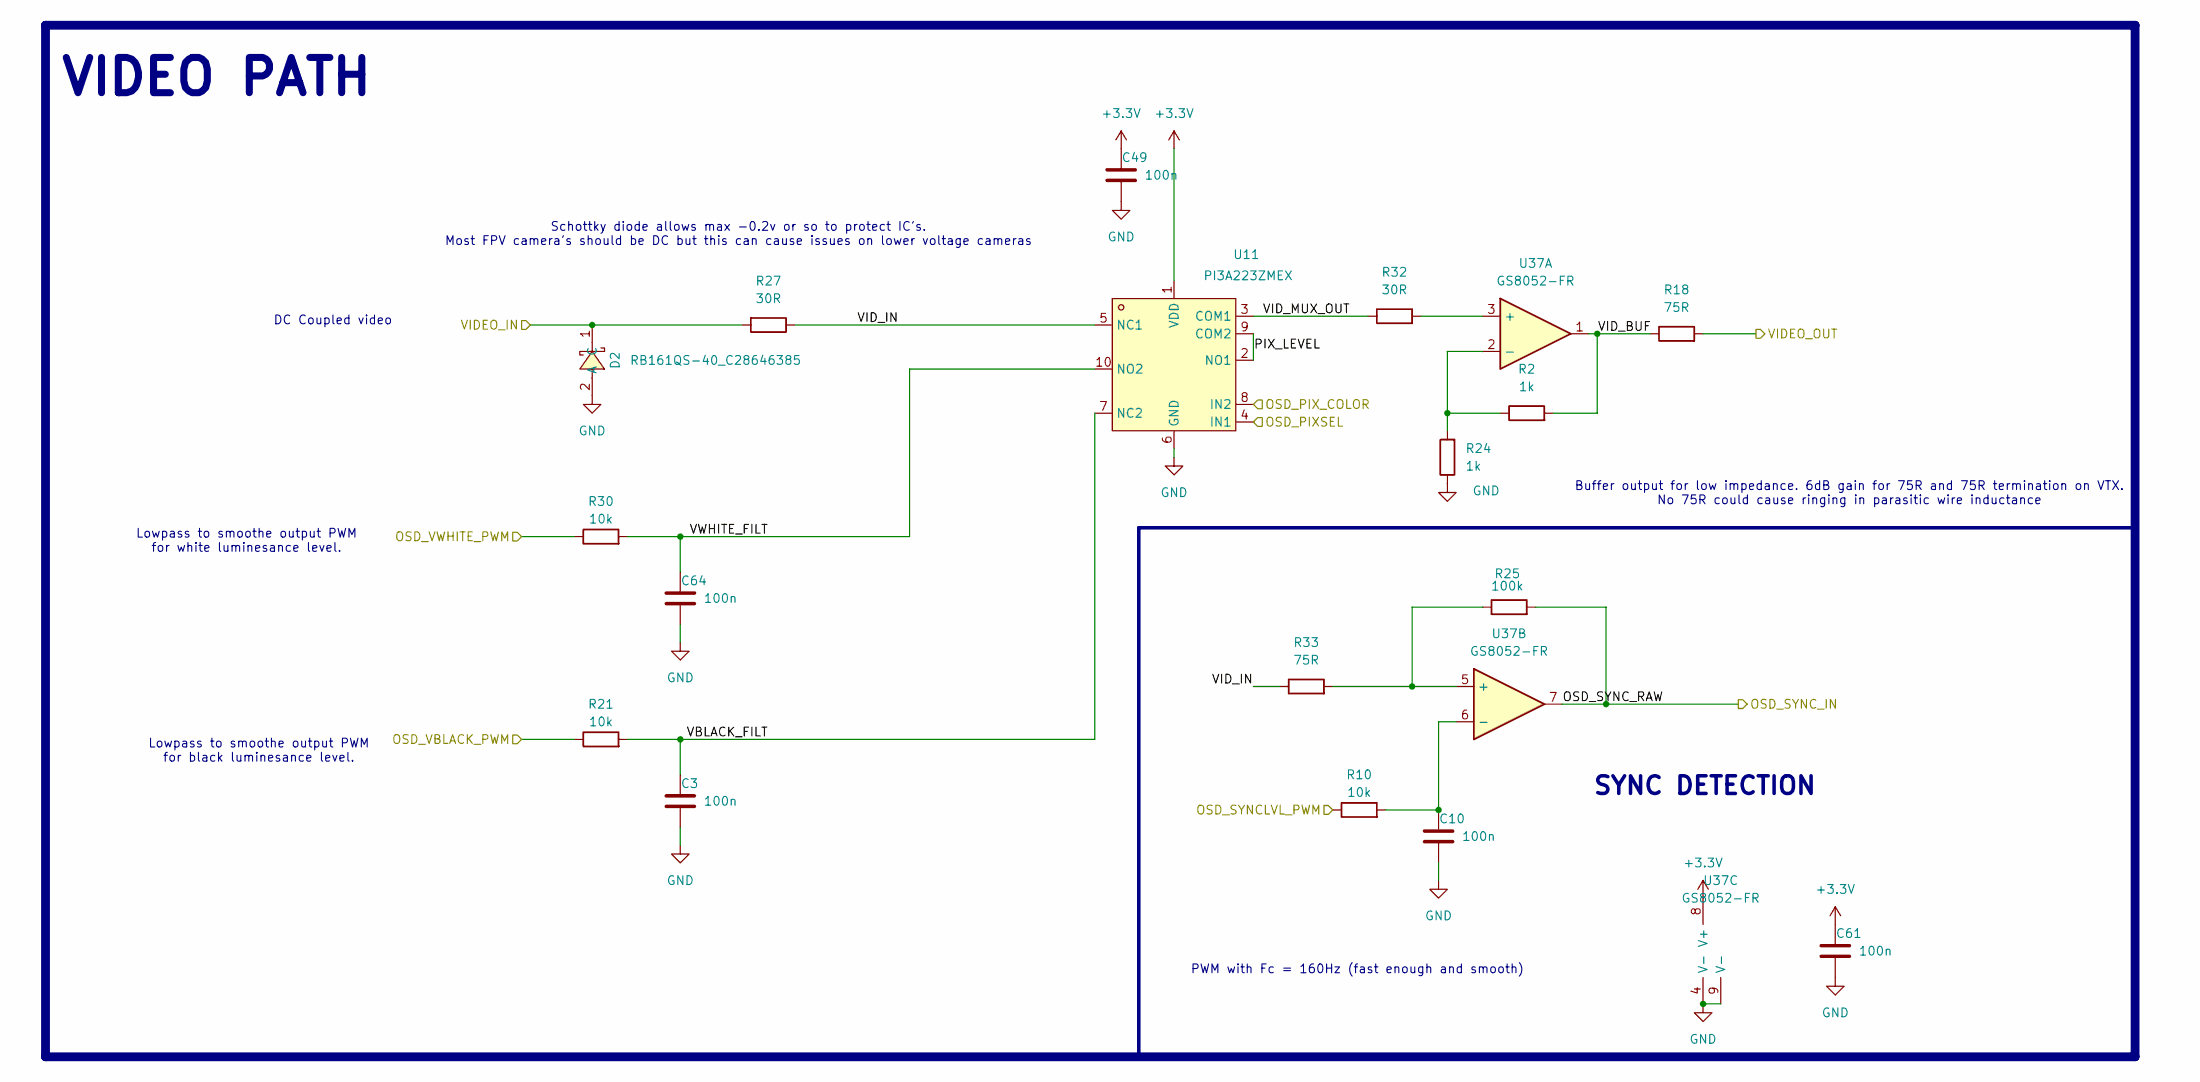
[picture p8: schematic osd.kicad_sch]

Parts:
C3, C10, C49, C61, C64: 100n; C_0201_0603Metric; LCSC C76939
D2: RB161QS-40_C28646385; SOD-882_L1.0-W0.6-RD; LCSC Part C28646385
R2, R24: 1k; C_0201_0603Metric; LCSC C270365
R10, R21, R30: 10k; C_0201_0603Metric; LCSC C473048
R18, R33: 75R; C_0201_0603Metric; LCSC C473570
R25: 100k; C_0201_0603Metric; LCSC C270364
R27, R32: 30R; C_0201_0603Metric; LCSC C778391
U11: PI3A223ZMEX; UQFN-10_L1.8-W1.4-P0.40-TL; LCSC Part C2673436
U37: GS8052-FR; WSON-8-1EP_2x2mm_P0.5mm_EP0.9x1.6mm; LCSC C605423

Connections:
+3.3V: C49.1, C61.1, U11.1 (VDD), U37.8 (V+); also elsewhere on the board
/OSD/OSD_PIXSEL: U11.4 (IN1); also elsewhere on the board
/OSD/OSD_PIX_COLOR: U11.8 (IN2); also elsewhere on the board
/OSD/OSD_SYNCLVL_PWM: R10.1; also elsewhere on the board
/OSD/OSD_SYNC_RAW: R25.2, U37.7; also elsewhere on the board
/OSD/OSD_VBLACK_PWM: R21.1; also elsewhere on the board
/OSD/OSD_VWHITE_PWM: R30.1; also elsewhere on the board
/OSD/PIX_LEVEL: U11.2 (NO1), U11.9 (COM2)
/OSD/VBLACK_FILT: C3.1, R21.2, U11.7 (NC2)
/OSD/VIDEO_IN: D2.1 (C), R27.2; also elsewhere on the board
/OSD/VIDEO_OUT: R18.2; also elsewhere on the board
/OSD/VID_BUF: R2.2, R18.1, U37.1
/OSD/VID_IN: R27.1, R33.1, U11.5 (NC1)
/OSD/VID_MUX_OUT: R32.1, U11.3 (COM1)
/OSD/VWHITE_FILT: C64.1, R30.2, U11.10 (NO2)
GND: C3.2, C10.2, C49.2, C61.2, C64.2, D2.2 (A), R24.1, U11.6 (GND), U37.4 (V-), U37.9 (V-); also elsewhere on the board
unnamed: R32.2, U37.3 (+)
unnamed: R2.1, R24.2, U37.2 (-)
unnamed: R25.1, R33.2, U37.5 (+)
unnamed: C10.1, R10.2, U37.6 (-)

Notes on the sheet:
PWM with Fc = 160Hz (fast enough and smooth)
DC Coupled video
Buffer output for low impedance. 6dB gain for 75R and 75R termination on VTX. No 75R could cause ringing in parasitic wire inductance
VIDEO PATH
SYNC DETECTION
Lowpass to smoothe output PWM for white luminesance level.
Lowpass to smoothe output PWM for black luminesance level.
Schottky diode allows max -0.2v or so to protect IC's. Most FPV camera's should be DC but this can cause issues on lower voltage cameras

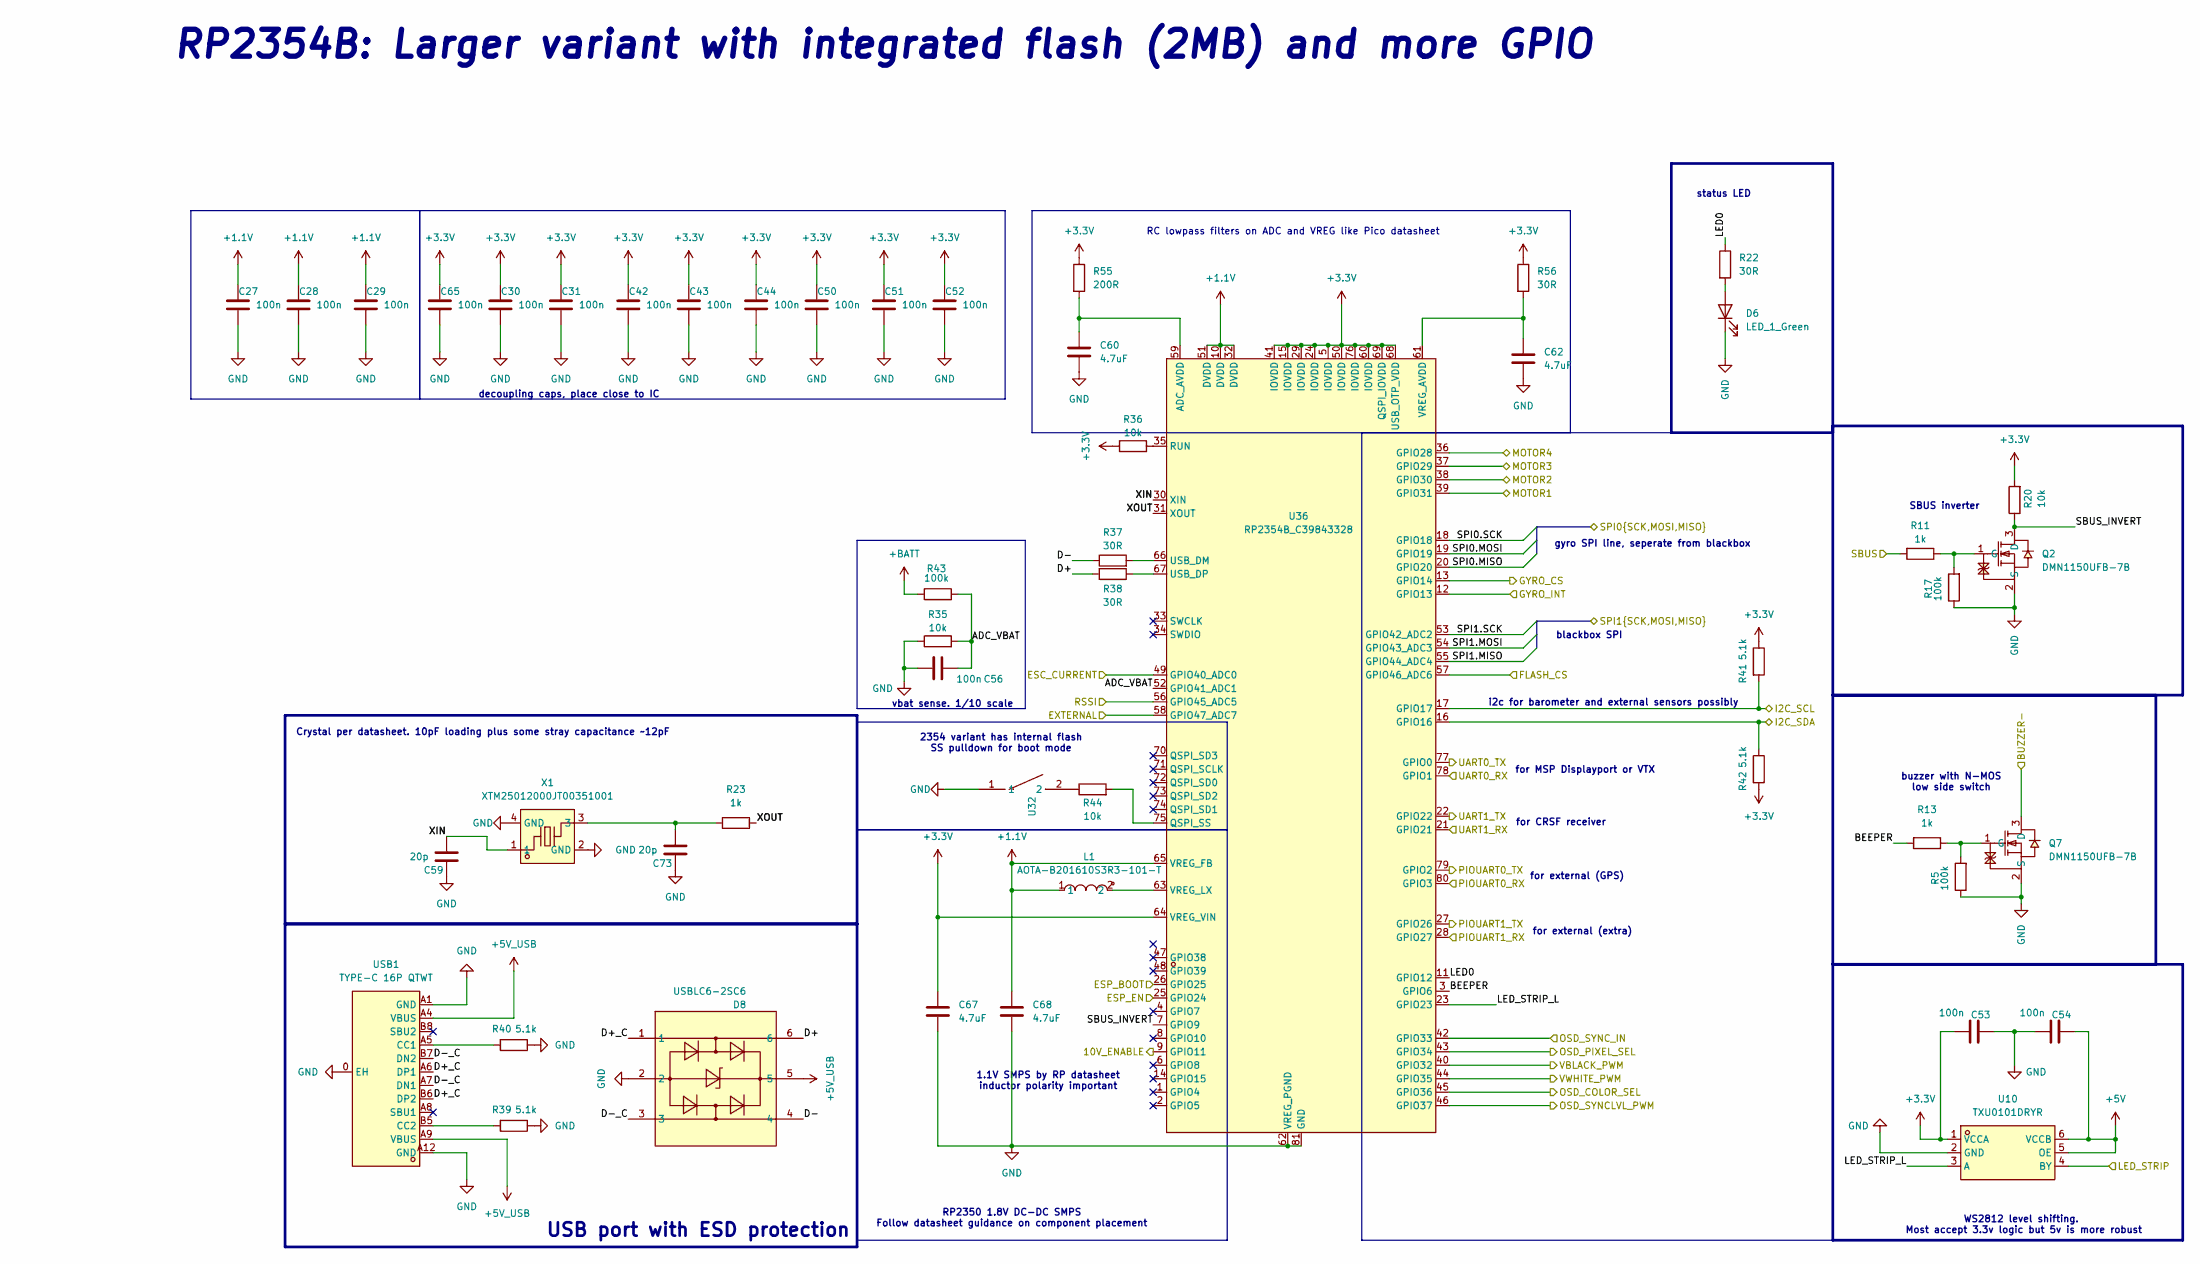
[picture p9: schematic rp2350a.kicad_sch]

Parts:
C27, C28, C29, C30, C31, C42, C43, C44, C50, C51, C52, C53, C54, C56, C65: 100n; C_0201_0603Metric; LCSC C76939
C59, C73: 20p; C_0201_0603Metric; LCSC C76923
C60, C62, C67, C68: 4.7uF; C_0402_1005Metric; LCSC C23733
D6: LED_1_Green; LED_0603_1608Metric; LCSC C2994781
D8: USBLC6-2SC6; SOT-666; LCSC Part C7519
L1: AOTA-B201610S3R3-101-T; IND-SMD_L2.0-W1.6_AOTA-B201610S3R3-101-T; LCSC Part C42411119
Q2, Q7: DMN1150UFB-7B; DFN-3L_L1.0-W0.6-P0.65-BR; LCSC Part C459538
R5, R17, R43: 100k; C_0201_0603Metric; LCSC C270364
R11, R13, R23: 1k; C_0201_0603Metric; LCSC C270365
R20, R35, R36, R44: 10k; C_0201_0603Metric; LCSC C473048
R22, R37, R38, R56: 30R; C_0201_0603Metric; LCSC C778391
R39, R40, R41, R42: 5.1k; C_0201_0603Metric; LCSC C270344
R55: 200R; C_0201_0603Metric; LCSC C270359
U10: TXU0101DRYR; SON-6_L1.5-W1.0-P0.50-TL; LCSC Part C5217869
U32: TS2306A 240GF MSM 9_C2976675; SW-SMD_4P-L3.0-W2.0-P0.85-LS3.5; LCSC Part C2976675
U36: RP2354B_C39843328; QFN-80_L10.0-W10.0-P0.40-TL-EP3.4; LCSC Part C39843328
USB1: TYPE-C 16P QTWT; USB-TYPE-C-SMD_TYPE-C-16P-QTWT; LCSC Part C5187472
X1: XTM25012000JT00351001; CRYSTAL-SMD_4P-L2.5-W2.0-BL-A; LCSC Part C37635340

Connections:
+1.1V: C27.1, C28.1, C29.1, C68.1, L1.1, U36.10 (DVDD), U36.32 (DVDD), U36.51 (DVDD), U36.65 (VREG_FB)
+3.3V: C30.1, C31.1, C42.1, C43.1, C44.1, C50.1, C51.1, C52.1, C53.1, C65.1, C67.1, R20.2, R36.1, R41.1, R42.2, R55.1, R56.1, U10.1 (VCCA), U36.5 (IOVDD), U36.15 (IOVDD), U36.24 (IOVDD), U36.29 (IOVDD), U36.41 (IOVDD), U36.50 (IOVDD), U36.60 (IOVDD), U36.64 (VREG_VIN), U36.68 (USB_OTP_VDD), U36.69 (QSPI_IOVDD), U36.76 (IOVDD); also elsewhere on the board
+5V: C54.2, U10.5 (OE), U10.6 (VCCB); also elsewhere on the board
+5V_USB: D8.5, USB1.A4 (VBUS), USB1.A9 (VBUS); also elsewhere on the board
+BATT: R43.1; also elsewhere on the board
/BLACKBOX/BB_CS: U36.57 (GPIO46_ADC6); also elsewhere on the board
/BLACKBOX/SPI1.MISO: U36.55 (GPIO44_ADC4); also elsewhere on the board
/BLACKBOX/SPI1.MOSI: U36.54 (GPIO43_ADC3); also elsewhere on the board
/BLACKBOX/SPI1.SCK: U36.53 (GPIO42_ADC2); also elsewhere on the board
/ELRS/ESP8285_EN: U36.25 (GPIO24); also elsewhere on the board
/ELRS/ESP_BOOT0: U36.26 (GPIO25); also elsewhere on the board
/I2C_SCL: R41.2, U36.17 (GPIO17); also elsewhere on the board
/I2C_SDA: R42.1, U36.16 (GPIO16); also elsewhere on the board
/IMU/GYRO_CS: U36.13 (GPIO14); also elsewhere on the board
/IMU/GYRO_INT: U36.12 (GPIO13); also elsewhere on the board
/IMU/SPI0.MISO: U36.20 (GPIO20); also elsewhere on the board
/IMU/SPI0.MOSI: U36.19 (GPIO19); also elsewhere on the board
/IMU/SPI0.SCK: U36.18 (GPIO18); also elsewhere on the board
/LED: U10.4 (BY); also elsewhere on the board
/OSD/OSD_PIXSEL: U36.43 (GPIO34); also elsewhere on the board
/OSD/OSD_PIX_COLOR: U36.45 (GPIO36); also elsewhere on the board
/OSD/OSD_SYNCLVL_PWM: U36.46 (GPIO37); also elsewhere on the board
/OSD/OSD_SYNC_RAW: U36.42 (GPIO33); also elsewhere on the board
/OSD/OSD_VBLACK_PWM: U36.40 (GPIO32); also elsewhere on the board
/OSD/OSD_VWHITE_PWM: U36.44 (GPIO35); also elsewhere on the board
/PADS/ADC2: U36.58 (GPIO47_ADC7); also elsewhere on the board
/PADS/BUZZER-: Q7.3 (D); also elsewhere on the board
/PADS/CURRENT: U36.49 (GPIO40_ADC0); also elsewhere on the board
/PADS/DIGITAL_RX: U36.78 (GPIO1); also elsewhere on the board
/PADS/DIGITAL_TX: U36.77 (GPIO0); also elsewhere on the board
/PADS/M1: U36.39 (GPIO31); also elsewhere on the board
/PADS/M2: U36.38 (GPIO30); also elsewhere on the board
/PADS/M3: U36.37 (GPIO29); also elsewhere on the board
/PADS/M4: U36.36 (GPIO28); also elsewhere on the board
/PADS/PIOUART0_RX: U36.80 (GPIO3); also elsewhere on the board
/PADS/PIOUART0_TX: U36.79 (GPIO2); also elsewhere on the board
/PADS/PIOUART1_RX: U36.28 (GPIO27); also elsewhere on the board
/PADS/PIOUART1_TX: U36.27 (GPIO26); also elsewhere on the board
/PADS/RSSI: U36.56 (GPIO45_ADC5); also elsewhere on the board
/PADS/SBUS: R11.2; also elsewhere on the board
/POWER/10V_ENABLE: U36.9 (GPIO11); also elsewhere on the board
/RP2350A/ADC_VBAT: C56.2, R35.2, R43.2, U36.52 (GPIO41_ADC1)
/RP2350A/BEEPER: R13.2, U36.3 (GPIO6)
/RP2350A/D+: D8.6, R38.2
/RP2350A/D+_C: D8.1, USB1.A6 (DP1), USB1.B6 (DP2)
/RP2350A/D-: D8.4, R37.1
/RP2350A/D-_C: D8.3, USB1.A7 (DN1), USB1.B7 (DN2)
/RP2350A/LED0: R22.1, U36.11 (GPIO12)
/RP2350A/LED_STRIP_L: U10.3 (A), U36.23 (GPIO23)
/RP2350A/SBUS_INVERT: Q2.3 (D), R20.1, U36.7 (GPIO9)
/RP2350A/XIN: C59.2, U36.30 (XIN), X1.1
/RP2350A/XOUT: R23.1, U36.31 (XOUT)
/UART1_RX: U36.21 (GPIO21); also elsewhere on the board
/UART1_TX: U36.22 (GPIO22); also elsewhere on the board
GND: C27.2, C28.2, C29.2, C30.2, C31.2, C42.2, C43.2, C44.2, C50.2, C51.2, C52.2, C53.2, C54.1, C56.1, C59.1, C60.2, C62.2, C65.2, C67.2, C68.2, C73.1, D6.1 (K), D8.2, Q2.2 (S), Q7.2 (S), R5.1, R17.1, R35.1, R39.1, R40.1, U10.2 (GND), U32.1, U36.62 (VREG_PGND), U36.81 (GND), USB1.0 (EH), USB1.A1 (GND), USB1.A12 (GND), X1.2 (GND), X1.4 (GND); also elsewhere on the board
unnamed: C73.2, R23.2, X1.3
unnamed: D6.2 (A), R22.2
unnamed: Q2.1 (G), R11.1, R17.2
unnamed: Q7.1 (G), R5.2, R13.1
unnamed: R44.1, U32.2
unnamed: C60.1, R55.2, U36.59 (ADC_AVDD)
unnamed: R44.2, U36.75 (QSPI_SS)
unnamed: R36.2, U36.35 (RUN)
unnamed: R37.2, U36.66 (USB_DM)
unnamed: R38.1, U36.67 (USB_DP)
unnamed: C62.1, R56.2, U36.61 (VREG_AVDD)
unnamed: L1.2, U36.63 (VREG_LX)
unnamed: R40.2, USB1.A5 (CC1)
unnamed: R39.2, USB1.B5 (CC2)

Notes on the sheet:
vbat sense. 1/10 scale
RP2354B: Larger variant with integrated flash (2MB) and more GPIO
blackbox SPI
buzzer with N-MOS low side switch
for MSP Displayport or VTX
2354 variant has internal flash SS pulldown for boot mode
RP2350 1.8V DC-DC SMPS Follow datasheet guidance on component placement
for CRSF receiver
gyro SPI line, seperate from blackbox
decoupling caps, place close to IC
for external (extra)
status LED
Crystal per datasheet. 10pF loading plus some stray capacitance ~12pF
for external (GPS)
i2c for barometer and external sensors possibly
SBUS inverter
RC lowpass filters on ADC and VREG like Pico datasheet
WS2812 level shifting. Most accept 3.3v logic but 5v is more robust
USB port with ESD protection
1.1V SMPS by RP datasheet inductor polarity important

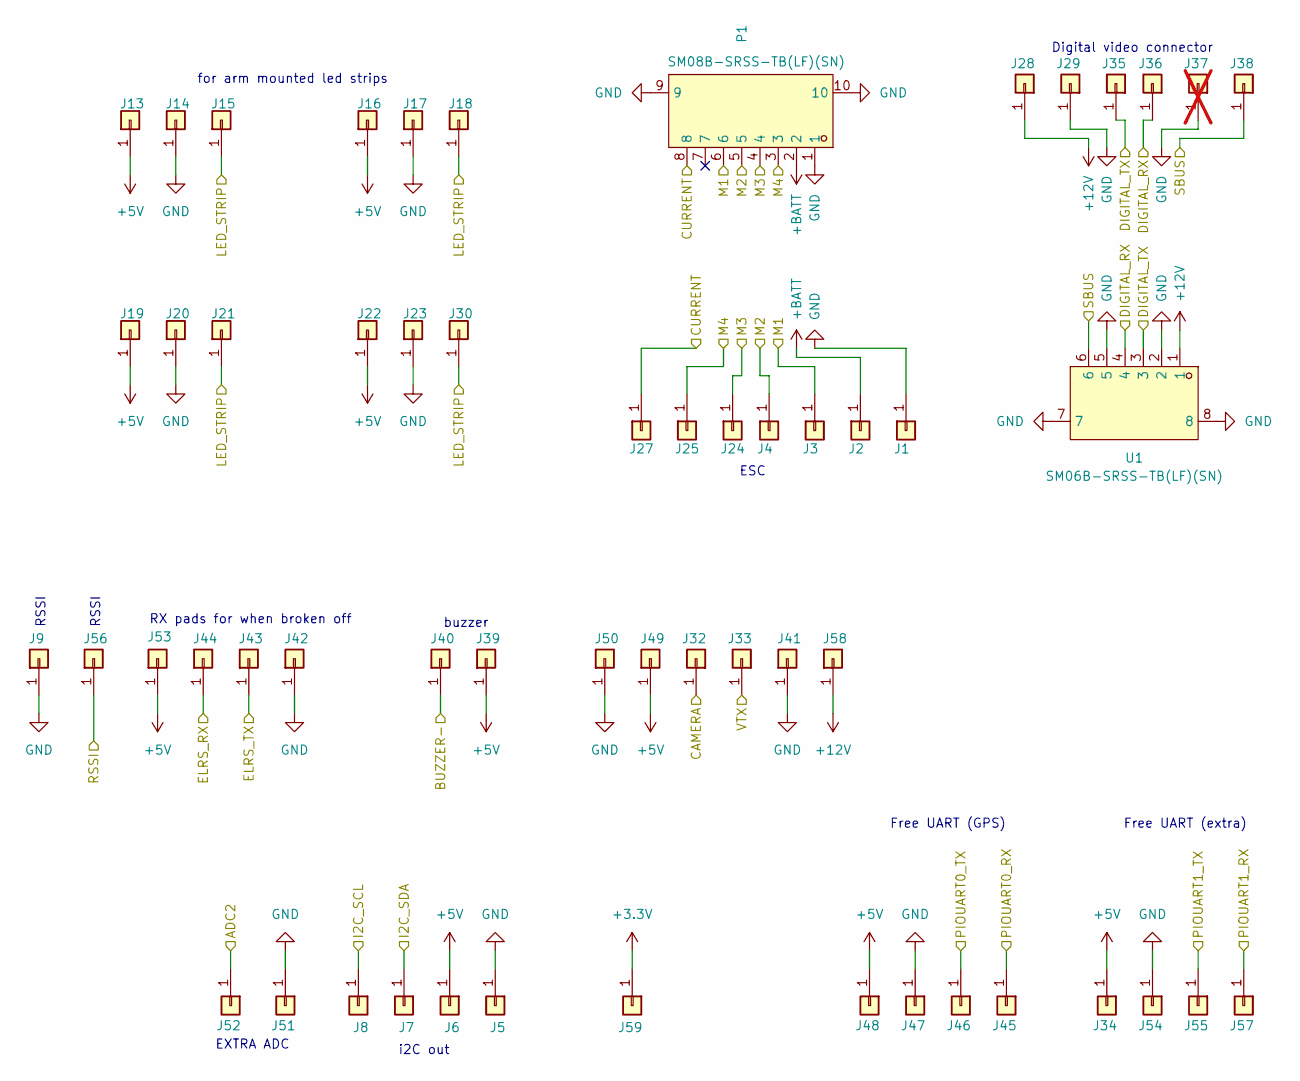
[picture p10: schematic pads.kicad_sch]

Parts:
J1, J2, J3, J4, J5, J6, J7, J8, J9, J13, J14, J15, J16, J17, J18, J19, J20, J21, J22, J23, J24, J25, J27, J28, J29, J30, J32, J33, J34, J35, J36, J38, J39, J40, J41, J42, J43, J44, J45, J46, J47, J48, J49, J50, J51, J52, J53, J54, J55, J56, J57, J58, J59: 5V; small_pad
J37: 5V; small_pad; not fitted
P1: SM08B-SRSS-TB(LF)(SN); CONN-TH_SM08B-SRSS-TB-LF-SN; LCSC Part C160407
U1: SM06B-SRSS-TB(LF)(SN); CONN-SMD_SM06B-SRSS-TB-LF-SN; LCSC Part C160405

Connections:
+3.3V: J59.1; also elsewhere on the board
+5V: J6.1, J13.1, J16.1, J19.1, J22.1, J34.1, J39.1, J48.1, J49.1, J53.1; also elsewhere on the board
+12V: J28.1, J58.1, U1.1; also elsewhere on the board
+BATT: J2.1, P1.2; also elsewhere on the board
/I2C_SCL: J8.1; also elsewhere on the board
/I2C_SDA: J7.1; also elsewhere on the board
/LED: J15.1, J18.1, J21.1, J30.1; also elsewhere on the board
/OSD/VIDEO_IN: J32.1; also elsewhere on the board
/OSD/VIDEO_OUT: J33.1; also elsewhere on the board
/PADS/ADC2: J52.1; also elsewhere on the board
/PADS/BUZZER-: J40.1; also elsewhere on the board
/PADS/CURRENT: J27.1, P1.8; also elsewhere on the board
/PADS/DIGITAL_RX: J36.1, U1.4; also elsewhere on the board
/PADS/DIGITAL_TX: J35.1, U1.3; also elsewhere on the board
/PADS/M1: J3.1, P1.6; also elsewhere on the board
/PADS/M2: J4.1, P1.5; also elsewhere on the board
/PADS/M3: J24.1, P1.4; also elsewhere on the board
/PADS/M4: J25.1, P1.3; also elsewhere on the board
/PADS/PIOUART0_RX: J45.1; also elsewhere on the board
/PADS/PIOUART0_TX: J46.1; also elsewhere on the board
/PADS/PIOUART1_RX: J57.1; also elsewhere on the board
/PADS/PIOUART1_TX: J55.1; also elsewhere on the board
/PADS/RSSI: J56.1; also elsewhere on the board
/PADS/SBUS: J38.1, U1.6; also elsewhere on the board
/UART1_RX: J44.1; also elsewhere on the board
/UART1_TX: J43.1; also elsewhere on the board
GND: J1.1, J5.1, J9.1, J14.1, J17.1, J20.1, J23.1, J29.1, J37.1, J41.1, J42.1, J47.1, J50.1, J51.1, J54.1, P1.1, P1.9, P1.10, U1.2, U1.5, U1.7, U1.8; also elsewhere on the board

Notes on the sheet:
RSSI
Free UART (GPS)
i2C out
Free UART (extra)
buzzer
RX pads for when broken off
ESC
Digital video connector
EXTRA ADC
for arm mounted led strips

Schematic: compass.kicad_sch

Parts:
C113: 100n; C_0402_1005Metric; LCSC C1525; not fitted
U31: LIS3MDLTR; LGA-12_L2.0-W2.0-P0.50-BL; LCSC Part C478483; not fitted

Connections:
unnamed: C113.1, U31.4 (C1), U31.5 (Vdd), U31.6 (Vdd_IO), U31.10 (CS)
unnamed: C113.2, U31.3 (GND), U31.9 (SD0/SA1)

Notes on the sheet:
Place far from magnetic interference sources

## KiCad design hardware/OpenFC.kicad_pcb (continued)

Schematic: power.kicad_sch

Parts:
C2, C16: 22uF; C_0402_1005Metric; LCSC C105226
C32, C33, C36, C39: 100n; C_0201_0603Metric; LCSC C76939
C35, C37: 4.7uF 50v; C_0805_2012Metric; LCSC C98192
C38, C40, C48: 22uF; C_0603_1608Metric; LCSC C2762594
D1, D4, D5, D7: LED_1_Green; LED_0603_1608Metric; LCSC C2994781
D3, D21: RB161QS-40_C28646385; SOD-882_L1.0-W0.6-RD; LCSC Part C28646385
L3, L4: XRTC303020D4R7MBCA; IND-SMD_L3.0-W3.0_AFE303020S; LCSC Part C39846837
Q1: DMN1150UFB-7B; DFN-3L_L1.0-W0.6-P0.65-BR; LCSC Part C459538
R4: 30R; C_0201_0603Metric; LCSC C778391
R7, R14, R16: 100k; C_0201_0603Metric; LCSC C270364
R8: 39k; C_0201_0603Metric; LCSC C473053
R12, R15: 200R; C_0201_0603Metric; LCSC C270359
R19: 10k; C_0201_0603Metric; LCSC C473048
R28: 5.23k; C_0201_0603Metric; LCSC C851767
R29: 470R; C_0201_0603Metric; LCSC C473464
R31: 13.7k; C_0201_0603Metric; LCSC C138175
U6, U7: LMR51420YFDDCR; SOT-23-6_L2.9-W1.6-P0.95-LS2.9-BL; LCSC Part C7296200
U13: TPS746-3.3DRV; WSON-6-1EP_2x2mm_P0.65mm_EP1x1.6mm; LCSC C2868202
U21: NCV8187AMT180TAG; WDFN-6_L2.0-W2.0-P0.65-BL-EP; LCSC Part C893189
U33: TPS2116DRLR; SOT-583-8_L2.1-W1.6-P0.50-LS1.6-BL; LCSC Part C3235557

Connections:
+1.8V_GYRO: C2.1, U21.5 (SNS), U21.6 (OUT); also elsewhere on the board
+3.3V: C16.1, R4.1, U13.1 (OUT); also elsewhere on the board
+5V: C32.1, C33.1, C48.1, D3.1 (C), R12.1, R19.2, U13.4 (EN), U13.6 (IN), U21.1 (IN), U21.2 (EN), U33.2 (VOUT), U33.7 (VOUT); also elsewhere on the board
+5V_BUCK: C40.1, D3.2 (A), L4.2, R7.2, R15.1, R16.2, U33.3 (VIN1), U33.5 (MODE)
+5V_USB: U33.6 (VIN2); also elsewhere on the board
+12V: C38.1, L3.2, R14.2, R29.1; also elsewhere on the board
+BATT: C35.1, C37.1, D21.1 (C), U6.3 (VIN), U7.3 (VIN), U7.5 (EN); also elsewhere on the board
/POWER/1.8V_PG: Q1.1 (G), R19.1, U21.4 (PG)
/POWER/10V_ENABLE: U6.5 (EN); also elsewhere on the board
GND: C2.2, C16.2, C32.2, C33.2, C35.2, C37.2, C38.2, C40.2, C48.2, D1.1 (K), D4.1 (K), D5.1 (K), D21.2 (A), Q1.2 (S), R8.2, R28.2, R31.2, U6.1 (GND), U7.1 (GND), U13.3 (GND), U13.5 (PG), U13.7 (EP), U21.3 (GND), U21.7 (EP), U33.1 (GND); also elsewhere on the board
unnamed: D1.2 (A), R15.2
unnamed: D4.2 (A), R4.2
unnamed: D5.2 (A), R29.2
unnamed: D7.2 (A), R12.2
unnamed: D7.1 (K), Q1.3 (D)
unnamed: C36.2, U6.6 (CB)
unnamed: R14.1, R28.1, U6.4 (FB)
unnamed: C36.1, L3.1, U6.2 (SW)
unnamed: C39.2, U7.6 (CB)
unnamed: R16.1, R31.1, U7.4 (FB)
unnamed: C39.1, L4.1, U7.2 (SW)
unnamed: R7.1, R8.1, U33.4 (PR1)

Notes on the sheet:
10V (2A)
3.3V 1A MAIN LDO
FPWM version of the LMR51420YFDDCR for less output ripple at low voltage and more consistency but less efficient
1.8V 150mA LDO (high PSRR)
5V (2A)
5V Power MUX
Switches up to 4A (TPS2117) from +5V_USB or +5V_BUCK to +5V. Prefers buck over USB, threshold voltage is about 3.5V. The threshold voltage is low to prevent accidental switchover to USB during peak consumption (worst case in flight). Emergency diode for if that happens during flight.

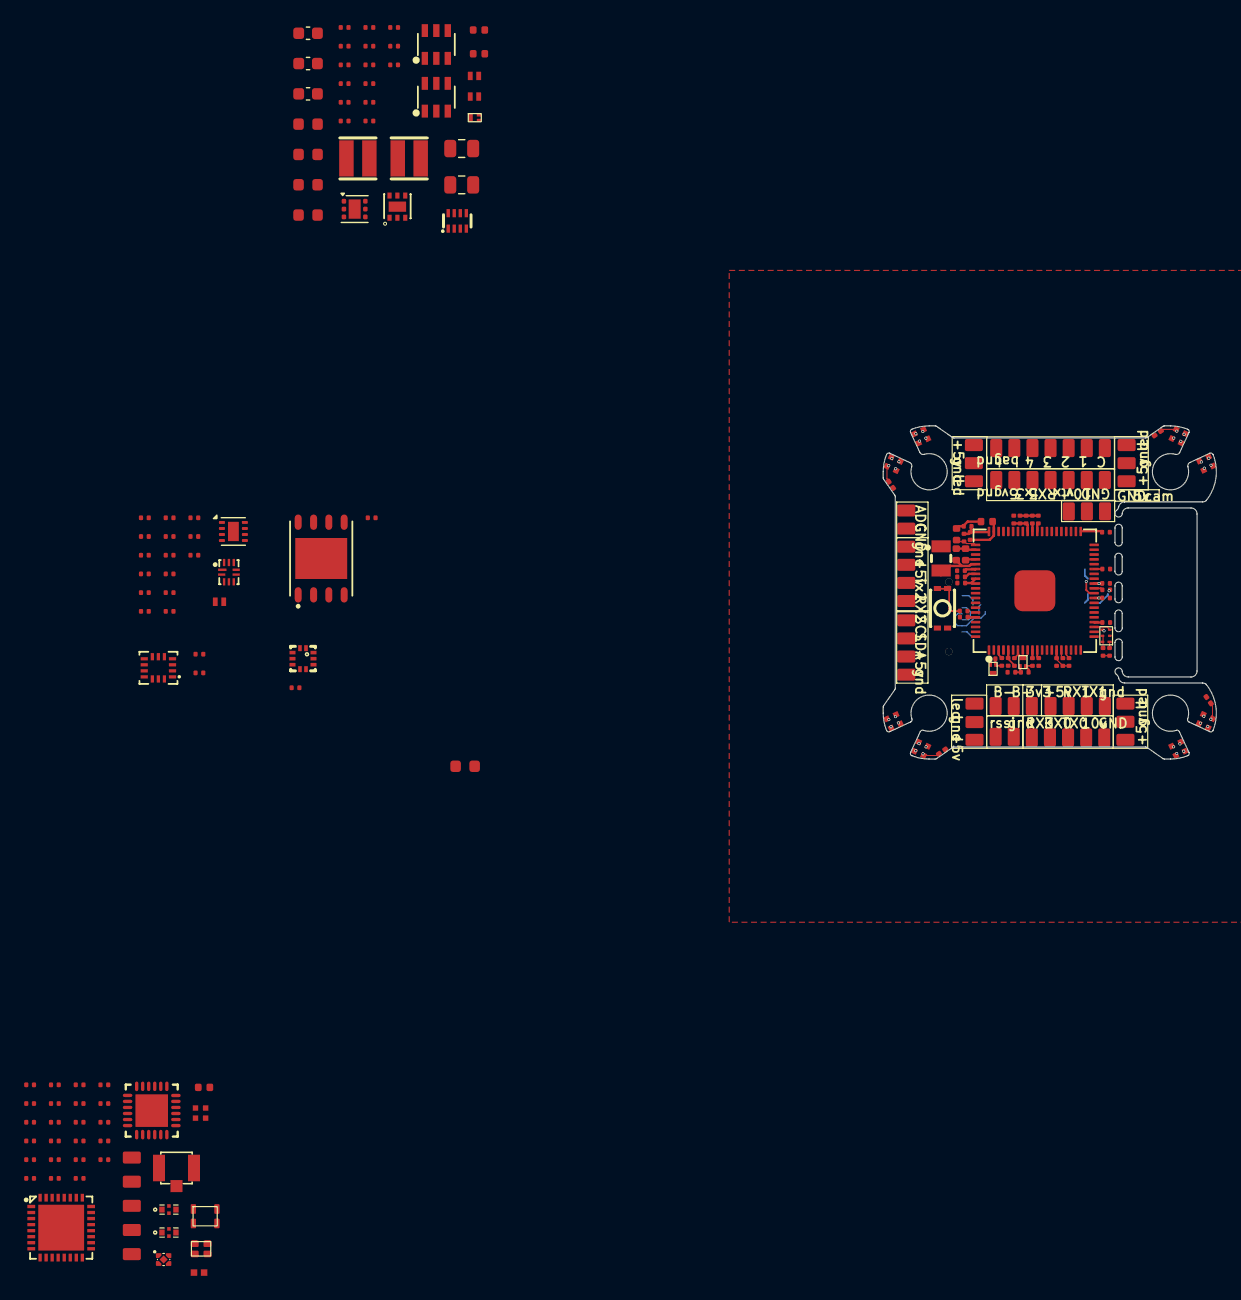
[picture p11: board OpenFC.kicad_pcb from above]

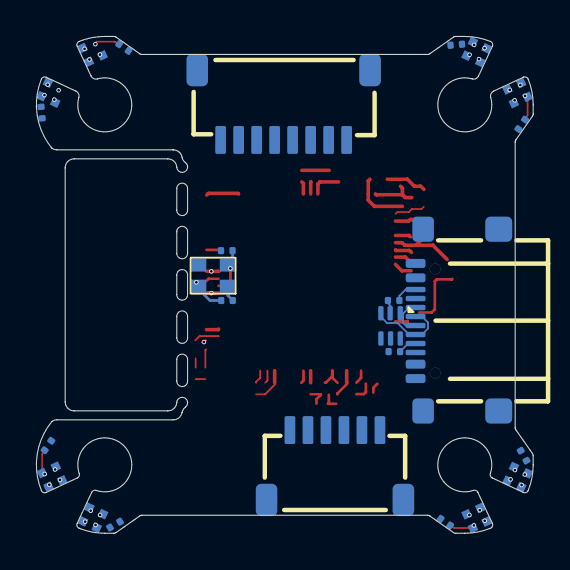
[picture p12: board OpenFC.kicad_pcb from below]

Board: 8 copper layers, 27.6 x 27.6 mm, 233 parts (25 on the bottom side), 130 nets.

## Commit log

2026-01-16 Initial commit: OpenFC flight controller
    Open-source Betaflight flight controller featuring:
    - RP2350A dual-core ARM Cortex-M33 microcontroller
    - Integrated break-off ELRS 2.4GHz receiver
    - LSM6DSV16XTR 6-axis IMU (gyro/accel)
    - BMP388 barometer
    - LIS3MDLTR magnetometer
    - W25Q128 16MB blackbox flash
    - 4x motor outputs, multiple UARTs, I2C, SPI
    - USB-C, addressable LEDs, buzzer output
    KiCad 9.0 design files included.
    [OpenFC.kicad_pcb, OpenFC.kicad_sch, Radioschematic.kicad_sch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]
2026-01-16 Update README to remove sensor specifications
    Removed barometer and magnetometer details from the sensors section.
2026-01-16 First routing
    [OpenFC.kicad_pcb, OpenFC.kicad_sch]
2026-01-17 Revised routing. All logic is routed just need uart and power planes
    [OpenFC.kicad_pcb]
2026-01-17 almost finished routing
    [OpenFC.kicad_pcb, OpenFC.kicad_sch, budgetrev2_bom.csv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]
2026-01-17 Final routing
    [OpenFC.kicad_pcb, leds.kicad_sch, power.kicad_sch]
2026-01-17 ESP XTAL routed with 1 via
    [OpenFC.kicad_pcb]
2026-01-17 fixed gyro power and rp2350 inductor
    [OpenFC.kicad_pcb, imu.kicad_sch, rp2350a.kicad_sch]
2026-01-17 added silkscreen graphics
    [OpenFC.kicad_pcb]
2026-01-17 as ordered
    [OpenFC.kicad_pcb, OpenFCv0.1_bom.csv, OpenFCv0.1_designators.csv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]
2026-01-18 Switched to RP2354A and re-routed
    [OpenFC-EdgeCuts.dxf, OpenFC-PasteBottom.dxf, OpenFC-PasteTop.dxf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]
2026-01-19 Added Open-OSD-X and new layout
    [OpenFC.kicad_pcb, OpenFC.kicad_sch, blackbox.kicad_sch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]
2026-01-22 Ordered first revision
    [OpenFC.csv, OpenFC.kicad_pcb, OpenFCv1.0_bom.csv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]
2026-01-23 Switched to RP2354B for V2 of the FC for more IO. I want to try implement OSD on PIO state machine. I know BF already uses all of them but it should be possible and then later try to combine it witht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
    [OpenFC.kicad_pcb, OpenFC.kicad_sch, OpenFCv2.0_bom.csv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]
2026-01-30 Cleaned up directory. Ordered first revision of FC (30x30) and cleaned up schematic
    [OpenFC-EdgeCuts.dxf, OpenFC-PasteBottom.dxf, OpenFC-PasteTop.dxf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]
2026-01-30 Revise README with updated hardware specifications
    Updated microcontroller and sensor specifications, added details for analog OSD, and revised connectivity information.
2026-01-31 switched to 0201
    [OpenFC.kicad_pcb, OpenFC.kicad_sch, baro.kicad_sch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]
